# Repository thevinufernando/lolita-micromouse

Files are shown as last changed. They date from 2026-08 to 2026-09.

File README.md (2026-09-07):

# Lolita Micromouse

<table align="center">
  <tr>
    <td align="center" valign="middle">
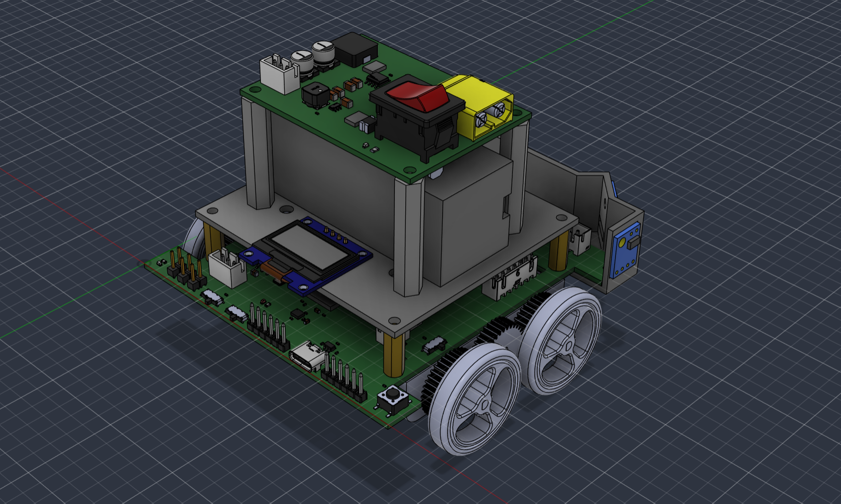
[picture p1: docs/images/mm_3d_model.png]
Lolita micromouse 3D model
      
    </td>
    <td width="24"></td>
    <td align="center" valign="middle">
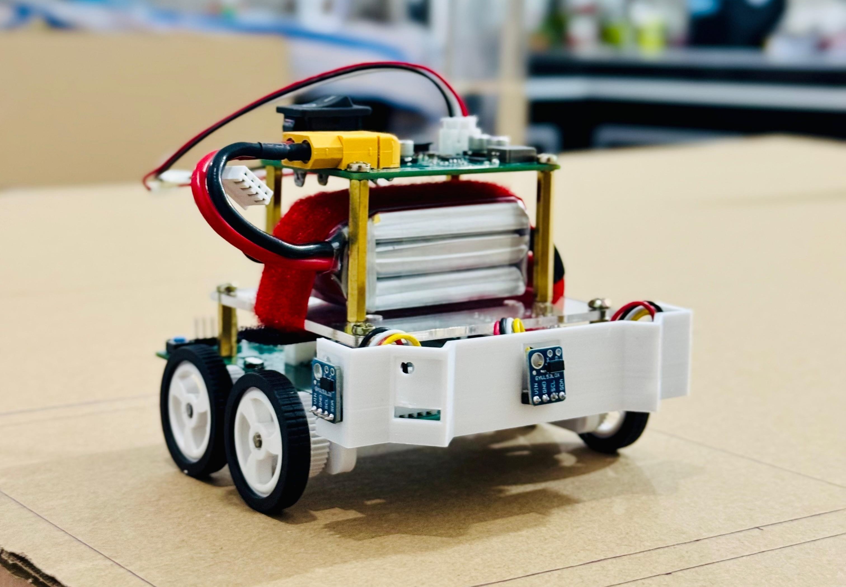
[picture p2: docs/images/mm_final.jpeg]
Lolita micromouse assembled robot
      
    </td>
  </tr>
</table>

## About

Lolita is a differential-drive micromouse robot built around an
**STM32F405RGT6** MCU, a 6-axis IMU, encoder-equipped DC motors, and five
VL53L0X time-of-flight sensors for wall detection. Two custom 4-layer PCBs
(a power board and a main controller board) handle regulation, sensing, and
motor drive, all housed in a custom-designed 3D-printed chassis.

The firmware runs low-level motion control — encoder-only straight-line
motion and IMU/encoder-fused turns via an EKF — as the foundation for future
maze-solving. See [`main_controller/`](main_controller) for firmware details
and [`pcb_designs/`](pcb_designs) for the electrical design.

## Workspace structure

| Folder | Contents |
|---|---|
| [`main_controller/`](main_controller) | STM32 firmware (CubeMX + HAL, CMake/Ninja build) |
| [`pcb_designs/`](pcb_designs) | Altium schematics, PCB layouts, and bring-up tests for the Power and Main PCBs |
| [`mechanical_designs/`](mechanical_designs) | Chassis and mechanical CAD |
| [`simulations/`](simulations) | Simulation work |
| [`tests/`](tests) | Project-level test resources |
| [`docs/`](docs) | Documentation assets (images, etc.) |

Each folder has its own `README.md` with further detail.

## Cloning and building

```sh
git clone git@github.com:thevinufernando/lolita_micromouse.git
cd lolita_micromouse
```

Firmware build instructions (toolchain setup, flashing, and debugging) are in
[`main_controller/README.md`](main_controller/README.md). Hardware design
files under `pcb_designs/` require [Altium Designer](https://www.altium.com/)
or the free [Altium 365 Viewer](https://www.altium.com/viewer).

## Team

- Thevinu Fernando
- Hiruna Malavipathirana
- Ishakya Ranhiru
- Chanul Nimadith

<!-- Team photo to be added -->

## License

This project is licensed under the [MIT License](LICENSE).

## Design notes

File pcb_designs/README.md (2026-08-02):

# PCB Designs

This folder contains the electrical design of the micromouse robot: schematics, PCB layouts, 3D renders, bring-up test media, and supporting design documents. The design is split into two boards — a **Power PCB** and a **Main Controller PCB** — connected by a board-to-board power harness.

All designs were done in Altium Designer. Both boards are **4-layer** PCBs.

## Folder structure

```
pcb_designs/
├── assets/                          # Schematic, layout, and 3D render images (used below)
├── docs/
│   └── LMR14030SDDAR_webench_reports/  # TI WEBENCH design reports for the 6V buck converter
├── main_PCB/
│   ├── schematics/                  # MM_2.0_sch.SchDoc + exported PDF
│   └── pcb/                         # MM_2.0_pcb.PcbDoc
├── power_PCB/
│   ├── schematics/                  # MM_2.0_power_sch.SchDoc + exported PDF
│   └── pcb/                         # MM_2.0_power_pcb.PcbDoc
└── tests/
    ├── main_PCB/                    # Bring-up photos/videos of the main PCB
    └── power_PCB/                   # Buck converter output tests (6V / 3.3V rails)
```

> Note: `.SchDoc` and `.PcbDoc` files require [Altium Designer](https://www.altium.com/) (or the free [Altium 365 Viewer](https://www.altium.com/viewer)) to open. PDF exports of the schematics are included alongside the source files for quick viewing without Altium.

## System overview

The robot is powered by a single **3S LiPO battery (11.1V nominal / 12.6V full charge)**. The Power PCB steps this down to the two rails the rest of the system needs, and the Main PCB carries the MCU, sensors, and motor drive electronics.

```
3S LiPO (12.6V) ──> Power PCB ──> +6V  (motors, via DRV8833)
                               └─> +3.3V (STM32, IMU, ToF sensors, OLED, logic)
```

---

## Power PCB

The Power PCB converts the raw battery voltage into two clean regulated rails using synchronous buck converters, with input reverse-polarity/overcurrent protection and a physical power switch.

### Key sections (see [power_PCB_sch.png](assets/power_PCB_sch.png))

| Section | Description |
|---|---|
| **Battery Power Supply** | XT60 connector (`J1`) brings in raw `VBAT` (3S LiPO, ~12.6V max). |
| **Circuit Protection** | Series power switch (`S1`), a resettable fuse (`F1`, 1812L300/24SLER) and a reverse-polarity/flyback protection diode (`D2`, PDS760-13) on the `VBAT_SW` → `VBAT_REG` path, with bulk input capacitance (`C12`). |
| **VBAT → +3.3V Conversion** | `AP63203WU-7` synchronous buck converter (`U1`) steps `VBAT_REG` down to a fixed **+3.3V** rail (`+3V3_BUCK`) for MCU/logic. |
| **VBAT → +6V Conversion** | `LMR14030SDDAR` synchronous buck converter (`U2`) steps `VBAT_REG` down to a regulated **+6V** rail (`+6V_BUCK`) for the drive motors. Output voltage is set via the `R2`/`R3` feedback divider. |
| **Power Output** | 3-pin JST connector (`J2`) exports `+6V_BUCK`, `+3V3_BUCK`, and `GND` to the Main PCB. |
| **Power LED** | `D3` indicator LED shows the board is powered from `VBAT_REG`. |

### Buck converter design notes

- **+3.3V rail — AP63203WU-7**: a simple fixed-frequency synchronous buck, chosen for the low-current 3.3V logic rail (MCU, sensors, OLED).
- **+6V rail — LMR14030SDDAR**: drives the higher-current motor rail. This converter was designed and simulated using **TI WEBENCH** — see [`docs/LMR14030SDDAR_webench_reports`](docs/LMR14030SDDAR_webench_reports) for the full design report, including:
  - `webench_sch.pdf` — WEBENCH-generated reference schematic
  - `WBDesign1_Steady State-1.pdf` — steady-state output ripple/efficiency
  - `WBDesign1_Bode Plot-2.pdf` — loop stability (gain/phase margin)
  - `WBDesign1_Startup-3.pdf` — startup/soft-start behavior
  - `WBDesign1_Input Transient-4.pdf` — response to input voltage transients

### Layout & 3D render

| Schematic | Layout | 3D View |
|---|---|---|
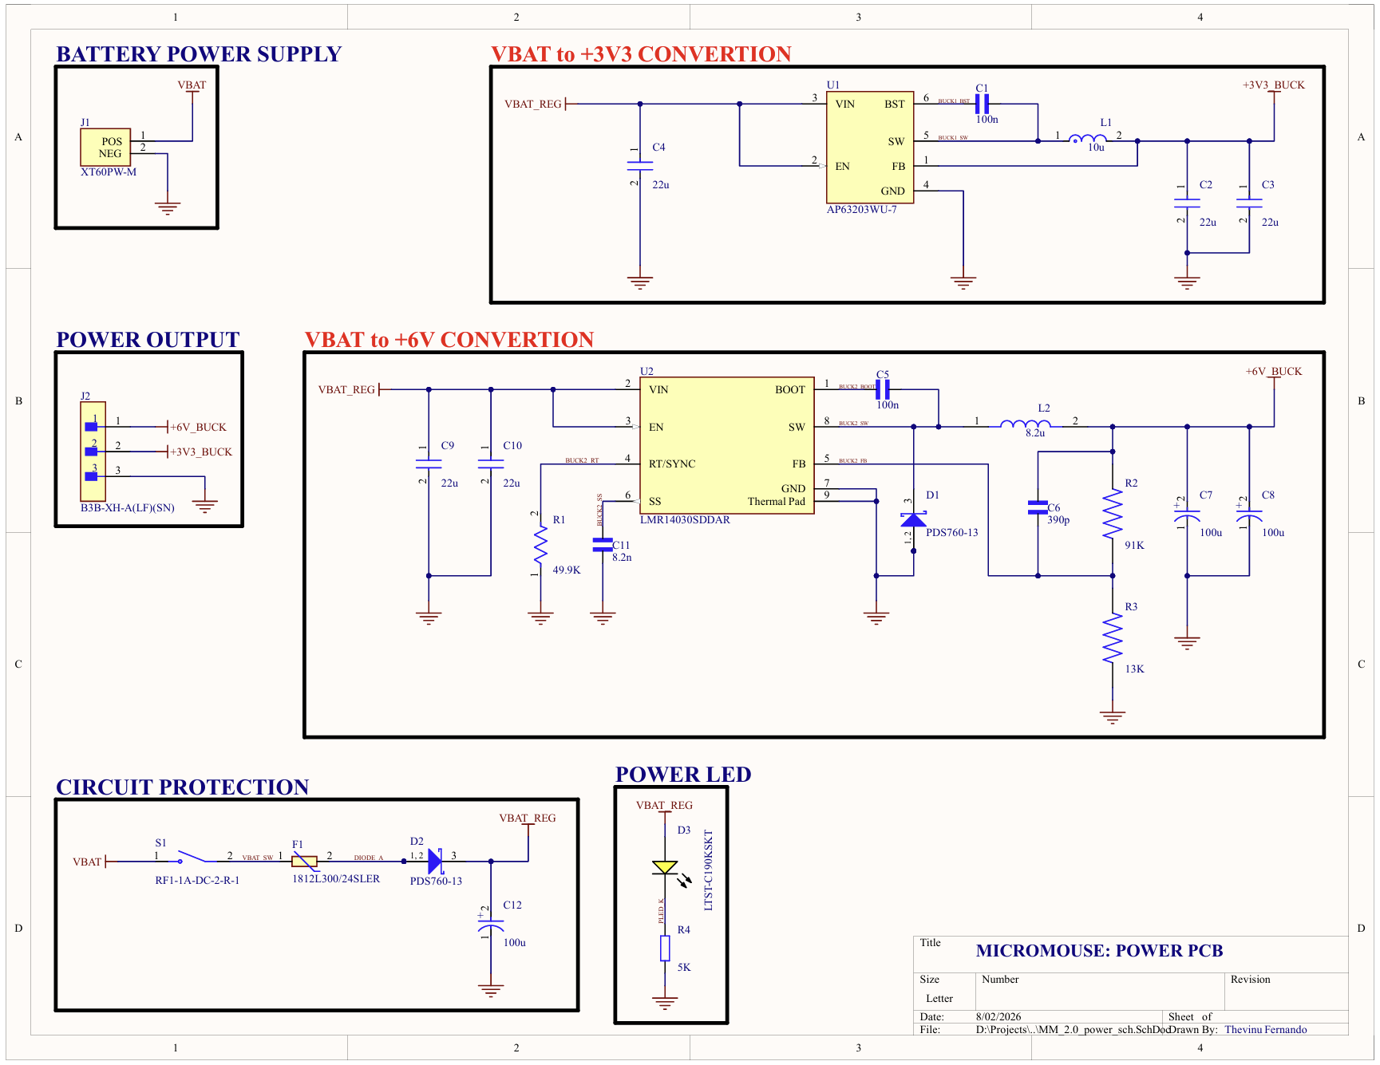
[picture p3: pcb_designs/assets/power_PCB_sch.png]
Power PCB Schematic
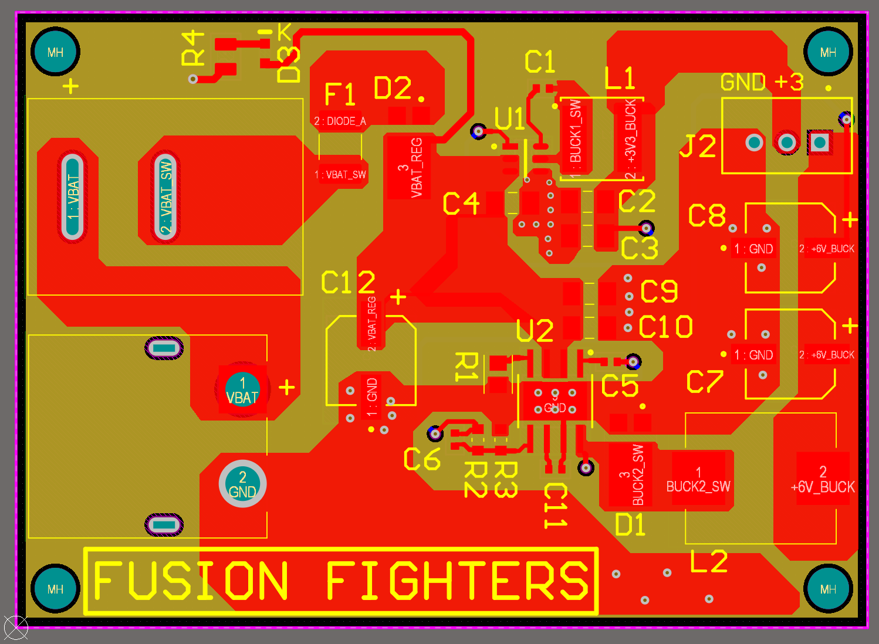
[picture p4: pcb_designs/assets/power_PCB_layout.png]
Power PCB Layout
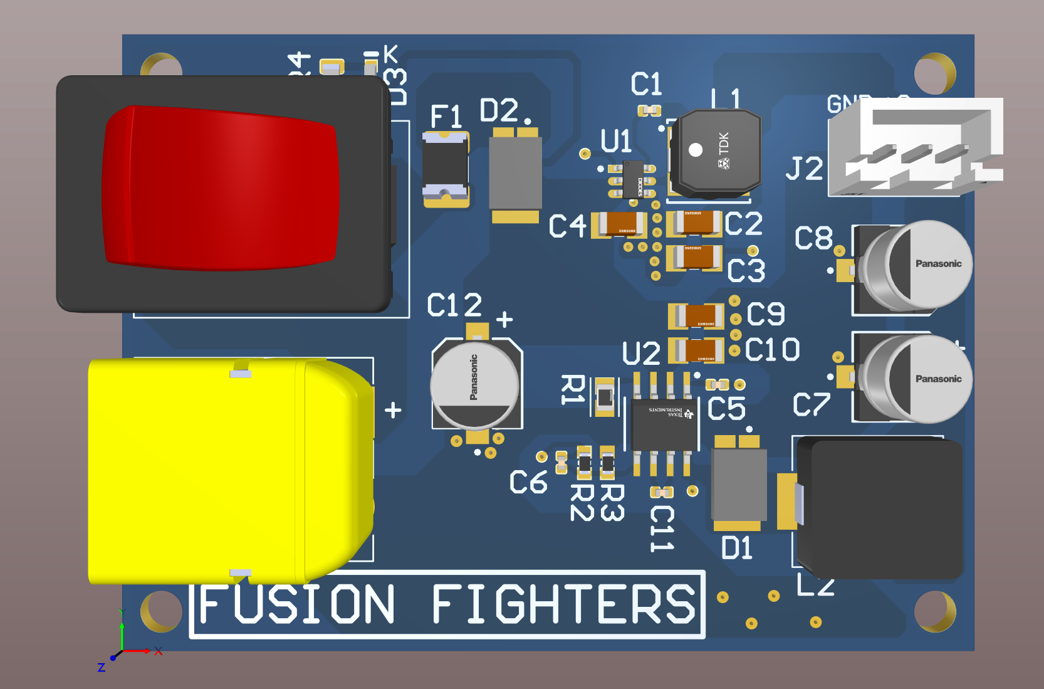
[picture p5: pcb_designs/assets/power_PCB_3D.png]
Power PCB 3D
|  |  |  |

### Bring-up testing

The Power PCB was bench-tested to verify both regulated rails before integrating with the Main PCB:

- [`tests/power_PCB/power_PCB_test.JPEG`](tests/power_PCB/power_PCB_test.JPEG) — test setup
- [`tests/power_PCB/6V_buck_test.MP4`](tests/power_PCB/6V_buck_test.MP4) — +6V rail verification
- [`tests/power_PCB/3.3V_buck_test.MP4`](tests/power_PCB/3.3V_buck_test.MP4) — +3.3V rail verification

---

## Main Controller PCB

The Main PCB carries the STM32F405RGT6 MCU, all sensing, motor driving, and the debug/expansion interfaces. It receives regulated +6V and +3.3V from the Power PCB.

### Key sections (see [main_PCB_sch.png](assets/main_PCB_sch.png))

| Section | Description |
|---|---|
| **MCU** | `STM32F405RGT6` (`U1A`/`U1B`) — main controller, running the firmware in [`main_controller/`](../main_controller). |
| **USB 2.0 (USB-C)** | USB-C receptacle with CC1/CC2 pull-downs for UFP detection, ESD protection (`USBLC6-2SC6`), and a `LDL1117S33R` LDO generating `+3V3_USB` for the USB PHY. |
| **Power Selection** | Jumper-selectable MCU supply source — `+3V3_USB` (from USB), `+3V3_EXT` (from the Power PCB), or `+3V3_DEBUG` (from an external debug supply). |
| **External Power Supply** | Direct `+6V_EXT` / `+3V3_EXT` input connector, for bench testing without the Power PCB. |
| **Inertial Measurement Unit** | `ICM-42688-P` 6-axis IMU (`U3`) over SPI, with its own 24MHz-independent decoupling and `IMU_INT` interrupt line to the MCU. |
| **VL53L0X ToF Sensors (I2C)** | Five VL53L0X time-of-flight distance sensors (`J4`–`J8`), one per wall-detection direction. |
| **TCA9548A I2C Mux** | 8-channel `TCA9548A` I2C multiplexer (`U4`). Since all VL53L0X units share the same default I2C address, each sensor is wired to its own mux channel so the MCU can address them individually over a single I2C bus. |
| **DRV8833 Motor Driver** | Dual H-bridge `DRV8833` driver ICs (one per motor, `J12`/`J13`) driving the left and right DC motors from the `+6V_EXT` rail, controlled via PWM from the MCU timers. |
| **Motors & Encoders (LM/RM)** | JST connectors (`J10`/`J11`) for the left/right motor + quadrature encoder channels (`ENC_CHA`/`ENC_CHB`) feeding the MCU's encoder timer inputs. |
| **OLED Display (I2C)** | 4-pin I2C header (`J9`) for a status/debug OLED. |
| **Debugging Interface** | SWD header (`J1`: `SWDIO`/`SWCLK`/`SWO`/`NRST`) for programming and debugging via ST-Link. |
| **BOOT0 / BOOT1 Mode Selection** | Slide switches to select MCU boot mode (system bootloader vs. flash) for DFU flashing. |
| **Mode Switches / External GPIO** | General-purpose slide switches (`MOD_SWA/SWB/SWM`) and a spare GPIO header (`J14`) for run-mode selection and future expansion. |
| **LED Indication** | Discrete status LEDs (`D2`/`D3`) driven directly from MCU GPIOs. |
| **Crystal / NRST / BOOT** | 24MHz HSE crystal (`X1`), reset button (`S5`), and boot-mode strapping circuitry for the MCU. |

### Layout & 3D render

| Schematic | Layout | 3D View |
|---|---|---|
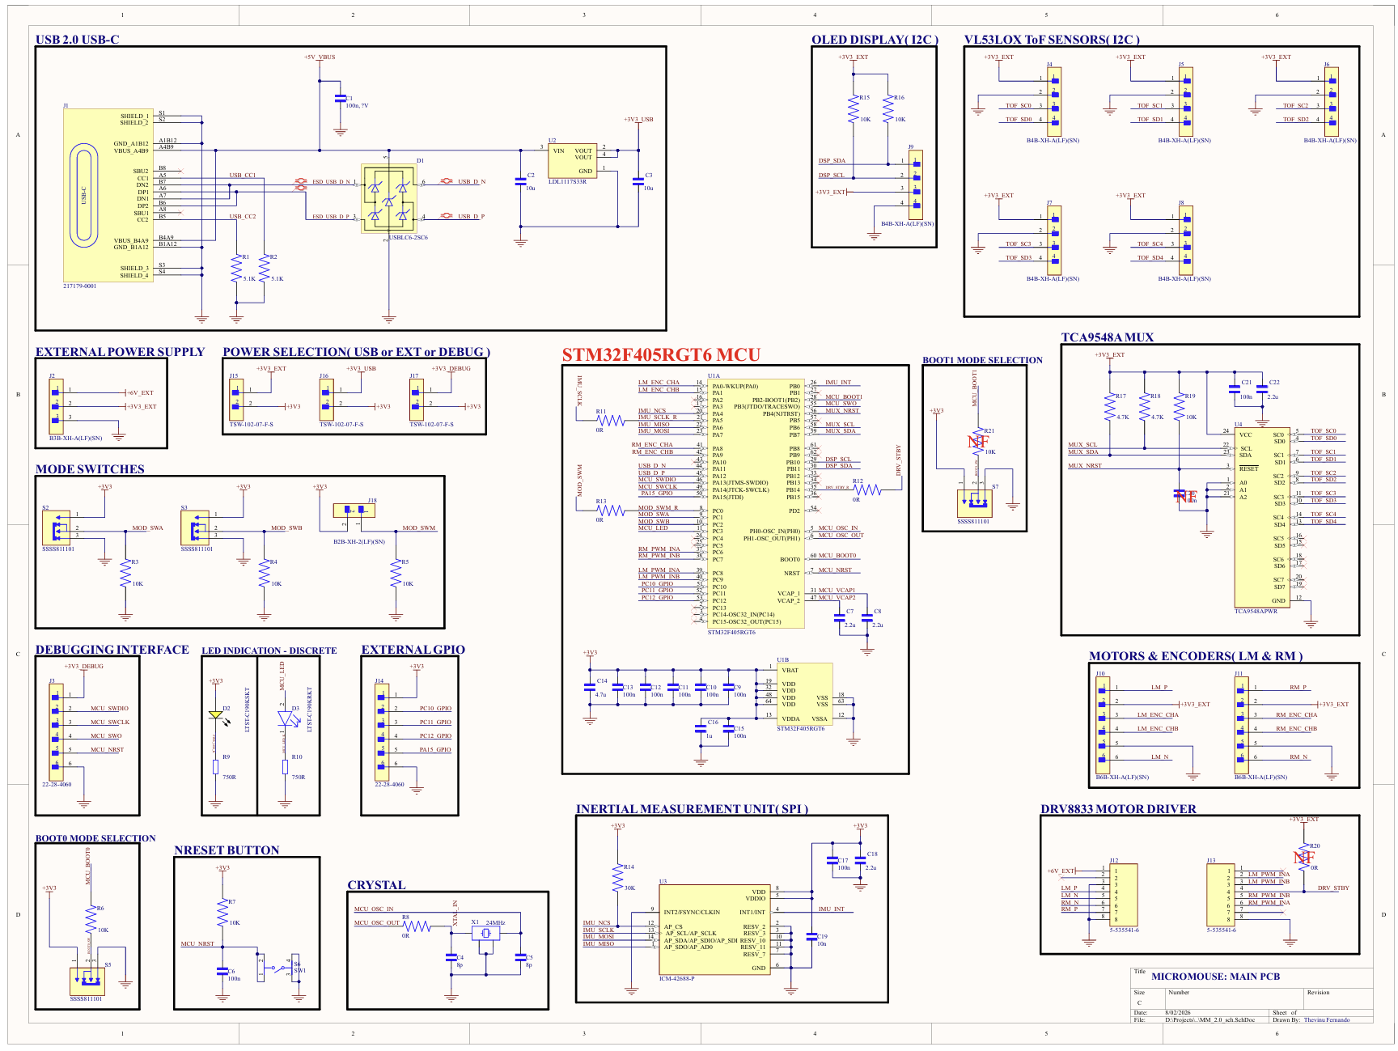
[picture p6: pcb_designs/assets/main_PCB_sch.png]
Main PCB Schematic
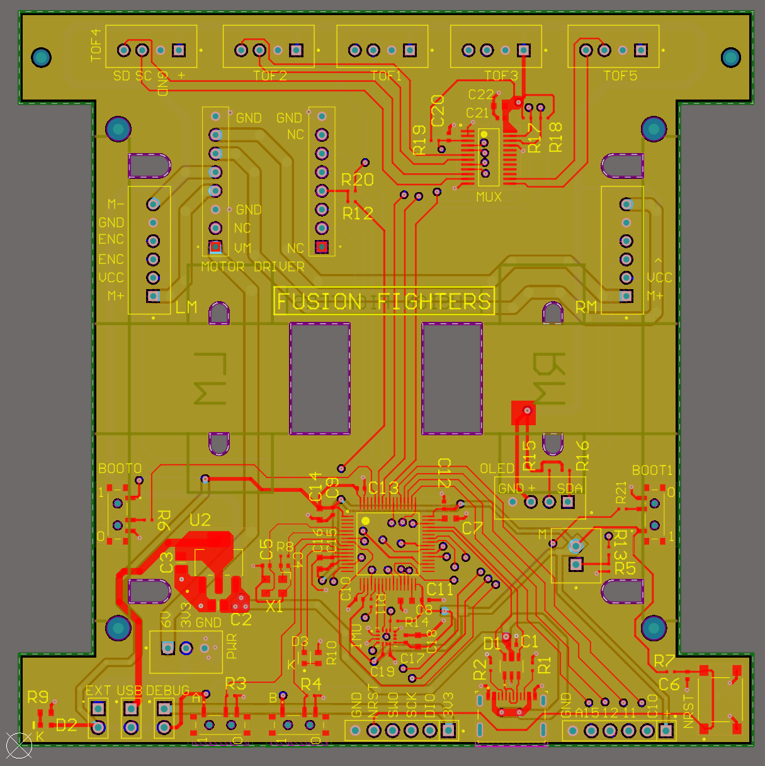
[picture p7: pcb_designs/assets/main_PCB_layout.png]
Main PCB Layout
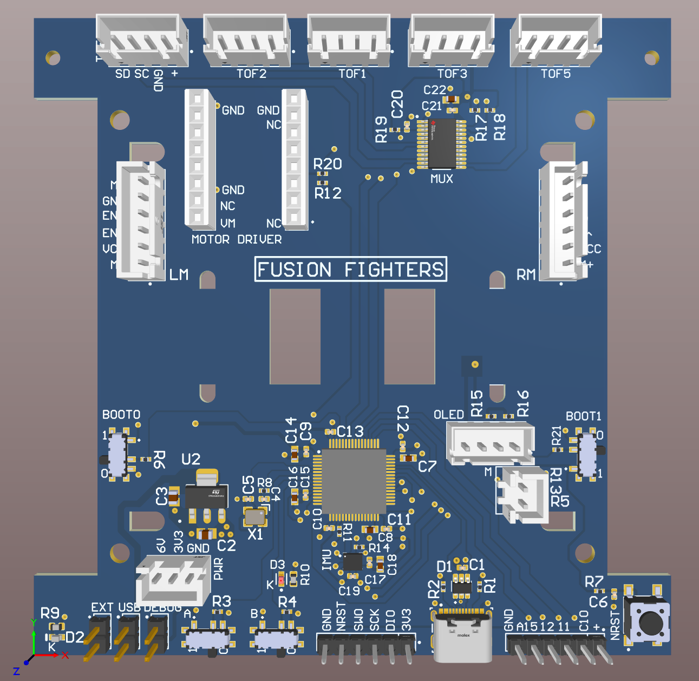
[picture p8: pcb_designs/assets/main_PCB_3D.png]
Main PCB 3D
|  |  |  |

### Bring-up testing

- [`tests/main_PCB/pcb_test_img.jpg`](tests/main_PCB/pcb_test_img.jpg) — assembled board
- [`tests/main_PCB/pcb_test.MP4`](tests/main_PCB/pcb_test.MP4) — power-up / basic functionality test
- [`tests/main_PCB/main_PCB_test.MP4`](tests/main_PCB/main_PCB_test.MP4) — extended functional test

---

## Design summary

| | Power PCB | Main PCB |
|---|---|---|
| Layers | 4 | 4 |
| Input | 3S LiPO (12.6V max) via XT60 | +6V / +3.3V from Power PCB (or external/USB) |
| Output | +6V, +3.3V | — |
| Key ICs | AP63203WU-7, LMR14030SDDAR | STM32F405RGT6, ICM-42688-P, TCA9548A, 5× VL53L0X, DRV8833 ×2 |
| CAD tool | Altium Designer | Altium Designer |

## Related documentation

- Firmware for the STM32F405RGT6 running on the Main PCB: [`main_controller/`](../main_controller) (see its `CLAUDE.md` for firmware development notes — **not covered by this document**).

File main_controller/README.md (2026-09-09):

# Main Controller — Firmware

This folder contains the firmware for the micromouse's main controller board:
an **STM32F405RGTx** (Cortex-M4F) running low-level motion control for the
differential-drive robot. It's built on **STM32CubeMX + HAL**, developed with
the **STM32Cube VSCode extension**, and built via **CMake + Ninja**.

> For the electrical design this firmware runs on, see
> [`pcb_designs/`](../pcb_designs) (Main Controller PCB section).

For the full technical reference used in day-to-day development — hardware
pin/peripheral map, sign/unit conventions, control architecture, tuning
procedure, hardware quirks, and change log — see **[CLAUDE.md](CLAUDE.md)**.
This README covers the same ground at a higher level plus environment setup.

---

## Current status

The robot is in **low-level controls bring-up**. Straight-line motion and
pivot turns are working and tunable. Maze-solving is **not implemented** and
out of scope until the motion primitives are trusted. The VL53L0X ToF sensors
are present on the PCB but not yet integrated into firmware.

## Hardware summary

| Part | Detail |
|---|---|
| MCU | STM32F405RGTx, Cortex-M4F, SYSCLK 96 MHz / **HCLK 48 MHz** |
| Motors | 2× N20 gear motor w/ quadrature encoder, differential drive |
| Motor driver | DRV8833 (IN/IN mode, 4 PWM channels) |
| IMU | ICM-42688-P (accel + gyro) over SPI1 — no magnetometer |
| Range | VL53L0X ToF ×5 — hardware present, not yet wired into firmware |
| Power | 3S LiPo, regulated by the companion Power PCB |

There is **no UART**. All runtime observation happens through the ST-Link
debugger's live-watch panel (`.vscode/launch.json` has the watch list
pre-populated), which is why the firmware exposes many `volatile` telemetry
globals.

## Firmware architecture

```
                 ┌──────────────┐
   encoders ────►│              │
                 │   EKF (yaw,  │──► fused yaw ──► turn PID ──► motors
   gyro Z ──────►│  gyro bias)  │
                 └──────────────┘

   encoders ────► distance PID ─┐
                                ├──► motors     (straight line, no IMU)
   encoders ────► heading  PID ─┘
```

- **Straight-line motion** is encoder-only by design.
- **Turns** fuse gyro + encoder odometry through a 2-state EKF (`[yaw, gyro_bias]`),
  running a multi-rate loop (~1 kHz gyro prediction, 100 Hz encoder
  correction + PID + motor output).
- All tuning constants live in a single file:
  `Core/Inc/Control/LowLevel/control_config.h`.
- `Core/Inc/Tests/test_harness.h` selects one of several on-target test
  routines (`ACTIVE_TEST`), implemented in `Core/Src/Tests/test_harness.c` —
  motor/encoder checks, straight-line tuning, turn tuning, IMU bring-up, etc.
  `main.c` itself only brings up hardware and calls `TestHarness_RunCycle()`.
  See [CLAUDE.md §6](CLAUDE.md#6-tuning-and-bring-up) for the full list and
  recommended bring-up order.

## Folder layout

```
main_controller/
├── Core/
│   ├── Inc, Src/
│   │   ├── Control/LowLevel/   PID.c  EKF.c  straightline_controller.c  turn_controller.c
│   │   │                       control_config.h  ← all tuning lives here
│   │   ├── Encoders/           encoders.c
│   │   ├── Motors/             DRV8833.c
│   │   ├── Sensors/ICM-42688-P/ ICM42688.c
│   │   ├── Tests/               test_harness.c  ← ACTIVE_TEST + all Test_* routines
│   │   └── Utils/               dwt_timer.c
├── Drivers/                    CMSIS + STM32F4xx HAL
├── cmake/                      Toolchain files + CubeMX-generated CMakeLists
├── tests/                      Host-side EKF verification harness (see tests/README.md)
├── main_controller.ioc         STM32CubeMX project file (pin/clock/peripheral config)
├── CMakeLists.txt              User source list — edit this to add files
├── CMakePresets.json           Debug / Release presets
└── STM32F405XX_FLASH.ld, startup_stm32f405xx.s
```

CubeMX owns the generated regions of `main.c` and all of
`cmake/stm32cubemx/CMakeLists.txt`. Hand-written code must stay inside
`/* USER CODE BEGIN x */ … /* USER CODE END x */` blocks or it will be
overwritten on the next CubeMX regeneration.

---

## Setup: STM32CubeIDE / STM32Cube extension for VSCode

This project is developed and built using the **STM32Cube for VSCode**
extension (ST's official STM32CubeIDE tooling brought into VSCode), not
standalone STM32CubeIDE.

### 1. Prerequisites

- [Visual Studio Code](https://code.visualstudio.com/)
- The **STM32Cube** extension pack from the VSCode Marketplace (search
  `STMicroelectronics` / `STM32Cube`). Installing it pulls in the required
  toolchain bundles (ARM GCC, CMake, Ninja, OpenOCD/ST-Link tools) under
  `%LOCALAPPDATA%\STM32Cube\bundles` — no separate STM32CubeIDE install is
  required.
- An **ST-Link** debug probe connected via the board's SWD header
  (`SWDIO`/`SWCLK`/`SWO`/`NRST`).
- (Optional, only if you need to regenerate peripheral init code)
  [STM32CubeMX](https://www.st.com/en/development-tools/stm32cubemx.html), to
  edit `main_controller.ioc`.

### 2. Open the project

1. Launch VSCode and open the `main_controller/` folder directly (this
   folder, not the repo root) — the extension expects the `.ioc` file,
   `CMakeLists.txt`, and `.vscode/` config at the workspace root.
2. The STM32Cube extension should auto-detect the project via
   `main_controller.ioc` and `.mxproject`. If prompted to configure CMake
   Tools, let it use the settings already checked into `.vscode/settings.json`
   (`cmake.cmakePath: cube-cmake`, Ninja generator).

### 3. Build

The extension drives CMake + Ninja under the hood using the `Debug` /
`Release` presets in `CMakePresets.json`. Use the extension's build button /
CMake Tools status bar, or run it manually.

To build from a shell instead, the ARM toolchain isn't on `PATH` by default —
add the bundled tools first:

```sh
BUNDLES="$LOCALAPPDATA/STM32Cube/bundles"
export PATH="$BUNDLES/gnu-tools-for-stm32/14.3.1+st.2/bin:$BUNDLES/ninja/1.13.2+st.1/bin:$PATH"
cmake --preset Debug        # only needed after adding/removing source files
cmake --build --preset Debug
```

The build must stay **warning-free**.

### 4. Flash and debug

Use the extension's **Run/Debug** panel (or `.vscode/launch.json`), which
flashes over the connected ST-Link and starts a debug session with the
pre-populated **live-watch** expression list — this is the primary way to
observe robot state, since there is no UART output.

> **Do not modify the `preBuild` / `imagesAndSymbols` settings in
> `.vscode/launch.json`.** Only the `liveWatch` expressions array is safe to
> edit freely (e.g. to add a new telemetry variable while tuning).

### 5. Adding a new source file

Two steps, both required, regardless of which tool you use to build:

1. Add it to `CMakeLists.txt` (`target_sources`, and
   `target_include_directories` if it's a new folder).
2. Re-run `cmake --preset Debug` (or reconfigure via the extension) so Ninja
   picks it up.

Never add user sources to `cmake/stm32cubemx/CMakeLists.txt` — it's
regenerated by CubeMX and anything added there is lost.

### 6. Regenerating peripheral code (STM32CubeMX)

If you need to change pin assignments, clocks, or enable a new peripheral,
edit `main_controller.ioc` in STM32CubeMX and regenerate. This rewrites
`cmake/stm32cubemx/` and the generated regions of `main.c`/HAL init files —
hand-written code inside `USER CODE` blocks is preserved, everything else is
not.

---

## Host-side tests

`tests/` contains a standalone host harness that compiles and exercises the
EKF (`Core/Src/Control/LowLevel/EKF.c`) on the development machine against
simulated sensor data, independent of the STM32 build. Run it after any
change to `EKF.c`:

```sh
gcc -O1 -o ekf_test.exe tests/ekf_host_test.c Core/Src/Control/LowLevel/EKF.c \
    -I Core/Inc/Control/LowLevel -lm
./ekf_test.exe
```

See [`tests/README.md`](tests/README.md) for what each test case covers.

---

## Conventions at a glance

Full detail is in [CLAUDE.md](CLAUDE.md) — summarized here:

- **Positive yaw = anticlockwise = left turn**, consistently across encoders,
  gyro, EKF, and PID.
- Distance in **cm**, turn angle in **degrees**, EKF yaw in **continuous,
  unwrapped radians**, motor speed **0–255 signed**.
- There is no magnetometer, so absolute heading is impossible — yaw is always
  relative to the last reset.

## Related documentation

- [CLAUDE.md](CLAUDE.md) — full firmware development reference (peripheral
  map, EKF derivation notes, tuning workflow, hardware quirks, change log).
- [`tests/README.md`](tests/README.md) — EKF host test details.
- [`../pcb_designs/README.md`](../pcb_designs/README.md) — electrical design
  this firmware targets.

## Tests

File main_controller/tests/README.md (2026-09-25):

# Host-side tests

Seven suites live here. Most compile real firmware sources on the development
machine and run them against simulated data, so they catch maths errors that
on-target testing cannot: on hardware you can only watch the output, whereas
here it can be compared against a known ground truth. The rest mirror logic that
cannot be linked on the host because it needs the HAL or the ST API, and pin the
RULE rather than the plumbing.

| Suite | Covers | Run after changing |
|---|---|---|
| `ekf_host_test.c` | Yaw EKF (gyro + encoder fusion) | `EKF.c` |
| `tof_filter_host_test.c` | VL53L0X noise filter | `tof_filter.c` |
| `tof_cache_host_test.c` | Held-reading age gate | `tof_sensors.c`, `TOF_MAX_SAMPLE_AGE_MS` |
| `motion_profile_host_test.c` | Trapezoidal profiles, mid-move retargeting, **moves that end at speed** | `motion_profile.c`, `CELL_DECISION_OFFSET_CM` |
| `maze_map_host_test.c` | Pose, wall bookkeeping, known-vs-open | `maze_map.c` |
| `navigator_host_test.c` | Reactive wall-following rule | `navigator.c` |
| `wall_follow_host_test.c` | Lateral loop and the cascade rule | `wall_follow.c`, the `WALL_FOLLOW_*` constants |
| `floodfill_goal_latch_test.c` | The goal-completion ordering window | `floodfill_run.c`, and upstream `Main.c` |
| `floodfill_diff.sh` | **That the ported flood fill IS the original** | anything under `Core/*/Maze/floodfill/` |

> **The maze state moved.** `v_walls`, `h_walls` and the pose are defined by the
> algorithm now (`Core/Src/Maze/floodfill/floodfill_run.c`), not by
> `maze_map.c`, so any test that links the map also has to link the algorithm
> and a stub API. The build lines below already do.

---

## EKF

`ekf_host_test.c` compiles the real `Core/Src/Control/LowLevel/EKF.c` on the
development machine and runs it against simulated sensor data. The EKF has no
hardware dependencies (it includes only `EKF.h`, `control_config.h` and
`math.h`), so it can be exercised without flashing the robot.

This is the only practical way to verify the filter maths. On-target you can
only observe the output; here you can compare it against a known ground truth.

## Running

Any host GCC will do (MSYS2 UCRT64 is what this project was developed with):

```sh
gcc -O1 -o ekf_test.exe tests/ekf_host_test.c Core/Src/Control/LowLevel/EKF.c \
    -I Core/Inc/Control/LowLevel -lm
./ekf_test.exe
```

Exit code is 0 when everything passes, 1 otherwise.

## What it covers

| Test | Checks |
|---|---|
| 1 | Gyro bias is recovered from a stationary run where the gyro reports rotation but the encoders do not |
| 2 | A clean 90 deg turn produces 90 deg of fused yaw |
| 3 | A 30% wheel-slip scale error is rejected: encoder-only would read 117 deg, fused reads ~90 |
| 4 | Yaw stays continuous past 360 deg and `EKF_NormalizeAngle` wraps correctly |
| 5 | `EKF_Reset` zeroes yaw but preserves the learned gyro bias |
| 6 | Zero, negative, huge and NULL inputs cannot corrupt the state |

Every test also asserts that the covariance matrix stays symmetric and
positive-definite, which is the usual early warning that a Kalman filter has
gone numerically wrong.

## Note on test 3

Test 3 is what drove the `EKF_R_SLIP_COEFF` design. With a fixed measurement
noise the filter tracked the slipping encoders to 100.4 deg, because
innovation gating only rejects sudden outliers and a steady slip ramp does not
look like one. Making R grow with the square of the rotation rate brought that
to 90.45 deg. If you ever set `EKF_R_SLIP_COEFF` to 0, expect this test to
fail - that is the test doing its job, not a bug.

---

## ToF noise filter

`tof_filter_host_test.c` exercises `Core/Src/Sensors/VL53L0X_Driver/tof_filter.c`.
It depends only on `tof_filter.h` and `control_config.h`, so it needs no
hardware and no ST API.

### Running

```sh
gcc -O1 -o tof_filter_test.exe tests/tof_filter_host_test.c     Core/Src/Sensors/VL53L0X_Driver/tof_filter.c     -I Core/Inc/Sensors/VL53L0X_Driver -I Core/Inc/Control/LowLevel -lm
./tof_filter_test.exe
```

The simulated noise band (83-90 mm for a true 80 mm target) is taken from an
actual bench measurement on this robot, so the test reflects the real sensor
rather than an invented noise model.

### What it covers

| Test | Checks |
|---|---|
| 1 | Jitter is actually reduced (sigma 2.27 mm -> 0.94 mm) and the mean is preserved |
| 2 | The filter does **not** remove bias - it settles at the biased mean, not the truth |
| 3 | A real wall transition (86 -> 250 mm) is passed through immediately, not ramped |
| 4 | Ordinary jitter never trips the jump detector |
| 5 | A lone outlier does not persist beyond one sample |
| 6 | A freshly-reset filter never reports a false close wall |
| 7 | `Invalidate()` re-seeds cleanly without blending across the gap |
| 8 | Zero, huge and NULL inputs cannot corrupt the filter |

### Note on tests 2, 3 and 5

**Test 2 asserts a limitation, deliberately.** Noise and bias are different
problems: no filter can remove a constant offset, because the average of
biased samples is equally biased. It exists so nobody tries to fix a constant
error by tuning filter constants. Bias belongs to `TOF_OFFSET_*_MM`.

**Test 3 caught a real design defect.** The jump detector originally compared
the *median* against the threshold. But a genuine step arrives as one new
value against a window of old ones - `{86, 86, 250}` medians to `86` - so the
median stage suppressed the first sample of every real transition exactly as
if it were an outlier, and the robot stayed blind to an opening for two
further samples. The detector now tests the **raw** sample. Do not "tidy" it
to use the median.

**Test 5 documents the cost of that fix.** A median cannot distinguish a bad
reflection from the first sample of a real change - they are the same shape -
so an outlier larger than the threshold produces one sample of overshoot
before the median pulls it back. The test asserts it does not persist rather
than that it never happens. A one-sample blip is much cheaper than being blind
to a real opening in the maze.

## tof_cache_host_test.c - the held-reading age gate

```sh
gcc -O1 -Wall -Wextra -o tof_cache_test tests/tof_cache_host_test.c \
    -I Core/Inc/Control/LowLevel -lm && ./tof_cache_test
```

Mirrors the decision `ToF_ReadAllLatest()` makes when a free-running sensor has
nothing new yet. The driver cannot run on the host -- it pulls in the ST API and
the HAL -- so what is pinned here is the rule rather than the plumbing.

The rule exists because continuous ranging and a 10 ms control loop do not tick
together: three polls in four legitimately find nothing new. Reporting that as
an invalid measurement is honest and useless, because the wall follower reads
invalid as "no wall" and would drop and re-acquire its reference several times a
second. So the newest good reading is held and served.

The age limit is the other half. Without it a dead sensor is indistinguishable
from one merely between measurements, and its last reading would be served
forever while the robot steers to a wall that is no longer there.

Also pins the unsigned-subtraction idiom against the tick counter's 32-bit wrap,
where a signed comparison would call a brand-new reading ancient.

## maze_map_host_test.c - pose, wall bookkeeping, known-vs-open

```sh
gcc -O1 -Wall -Wextra -o maze_map_test tests/maze_map_host_test.c \
    Core/Src/Maze/maze_map.c Core/Src/Maze/floodfill/maze.c \
    Core/Src/Maze/floodfill/floodfill_run.c tests/floodfill_sim_api.c \
    -DSIM_PROVIDE_DEBUG_LOG -I Core/Inc/Maze -I Core/Inc/Maze/floodfill \
    && ./maze_map_test
```

Covers the direction arithmetic in both directions -- `MazeMap_CellWalls()`
must read back exactly what `MazeMap_UpdateWalls()` wrote, from all four
headings -- and the distinction between a cell with no walls and a cell nobody
has looked at. Getting the first wrong produces a map that is plausible,
self-consistent and mirrored; getting the second wrong makes every unexplored
cell read as wide open.

## floodfill_diff.sh - is the ported algorithm the same algorithm?

```sh
tests/floodfill_diff.sh [path-to-MicroMouseAlgorithm]
```

The one test that matters for the port. It builds `MicroMouseAlgorithm`'s
`maze.c` + `Main.c` into one binary and the copies under
`Core/{Inc,Src}/Maze/floodfill/` into another, links BOTH against the same
simulated maze in `floodfill_sim_api.c`, and compares their transcripts action
for action across seven seeded mazes.

Everything about the two builds is identical except which copy of the algorithm
they contain. So "the algorithm did not change" stops being a claim and becomes
something the build either proves or fails. Run it after touching anything
under `floodfill/`, and if it ever diverges, change
`MicroMouseAlgorithm` first and re-port rather than patching the copy.

It also runs every maze twice, once serving wall readings fresh and once from a
per-cell snapshot. The snapshot is the single adaptation the robot needed -- a
real sensor read costs about 200 ms and the algorithm asks several times per
cell -- and the transcripts must match, or the caching is changing behaviour
rather than just saving time.

The mazes come from a seeded recursive backtracker, so both binaries carve the
identical one and there are plenty of dead ends for `checkDeadEnd()` to find.

## navigator_host_test.c - reactive wall-following rule

```sh
gcc -O1 -Wall -Wextra -o nav_test tests/navigator_host_test.c \
    Core/Src/Maze/maze_map.c Core/Src/Maze/floodfill/maze.c \
    Core/Src/Maze/floodfill/floodfill_run.c tests/floodfill_sim_api.c \
    -DSIM_PROVIDE_DEBUG_LOG -I Core/Inc/Maze -I Core/Inc/Maze/floodfill \
    && ./nav_test
```

Checks the decision rule's truth table, then drives it around a simulated
arena through the real `maze_map.c` and asserts the recorded walls match.

**It caught the defining bug in that rule.** The first version returned "turn
right" as a complete action. The trace showed the robot reaching the opening,
turning into it, seeing another open right, and pivoting straight back down
the corridor it came from without ever entering the new cell. Every action a
wall follower takes must end in one cell of forward motion; the turn only
chooses which way to leave. This is the classic way the rule is written wrong,
and on hardware it would have looked like a turn-tuning problem rather than a
logic error.

The rule itself is copied into the test rather than linked, because
`navigator.c` needs the HAL and cannot build on the host. The constants come
from the real `navigator.h`, so the test also proves that header parses
standalone and that `MazeTrace_t` still satisfies its 40-byte stride assert.

---

## motion_profile_host_test.c - the chained-motion cases

```sh
gcc -O1 -Wall -Wextra -o prof_test tests/motion_profile_host_test.c \
    Core/Src/Control/LowLevel/motion_profile.c \
    -I Core/Inc/Control/LowLevel -lm && ./prof_test
```

Tests 8 to 10 cover `MotionProfile_InitFromTo()`, which is what continuous cell
motion is built on. They are worth calling out because a mistake in any of them
is invisible on a bench and expensive in a maze:

| Test | Checks |
|---|---|
| 8 | A cruise-to-cruise segment has NO ramps, takes exactly distance/speed, and beats the same cell driven rest-to-rest |
| 9 | The two ends of a chained corridor: leaving a centre accelerates and never decelerates; the stop before a turn comes to rest exactly at the centre with cruise to spare |
| 10 | A speed change with no room for it is REFUSED, and what gets built is the hardest stop rather than a reversal -- in both directions, plus a `v_end` pointing backwards |

A profile that quietly decelerated to rest anyway would look like the robot
merely being slow. One that overshot its distance would put the robot past the
point it can still stop at before a turn, which this chassis cannot recover
from -- it has no reverse.

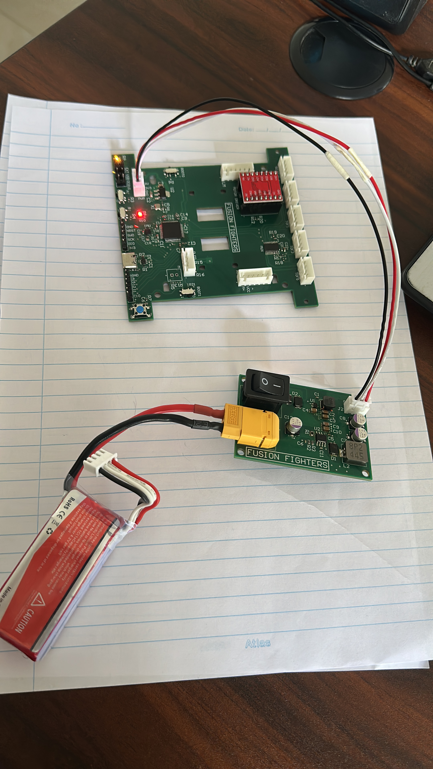
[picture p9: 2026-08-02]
pcb_designs/tests/main_PCB/pcb_test_img.jpg

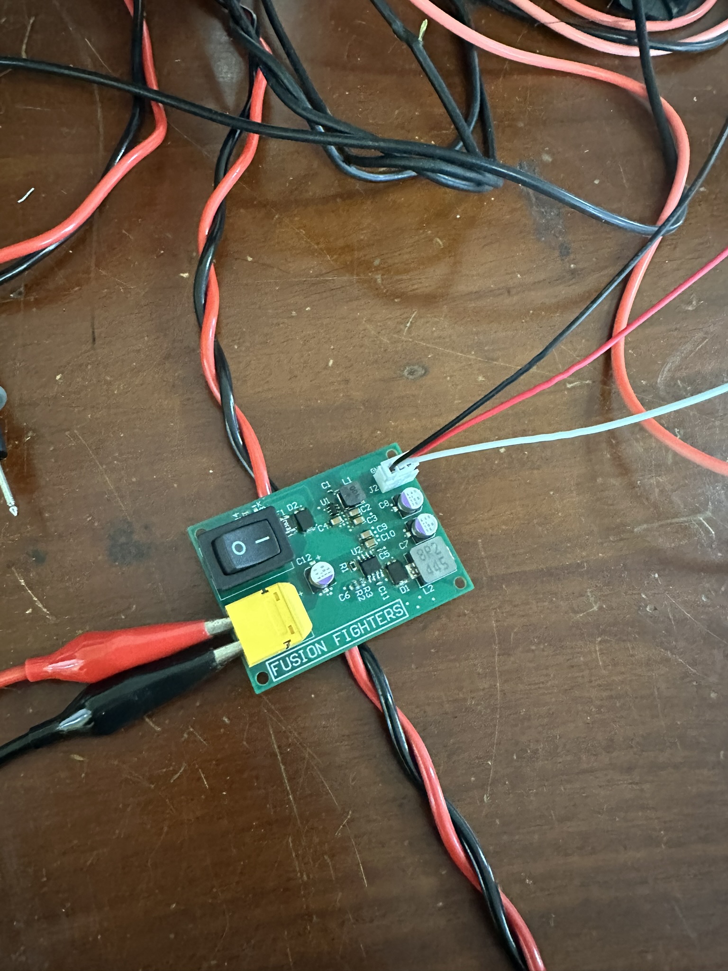
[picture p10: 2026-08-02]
pcb_designs/tests/power_PCB/power_PCB_test.JPEG

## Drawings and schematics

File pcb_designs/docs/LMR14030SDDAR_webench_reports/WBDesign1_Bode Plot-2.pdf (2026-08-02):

## WEBENCH ® Design Report

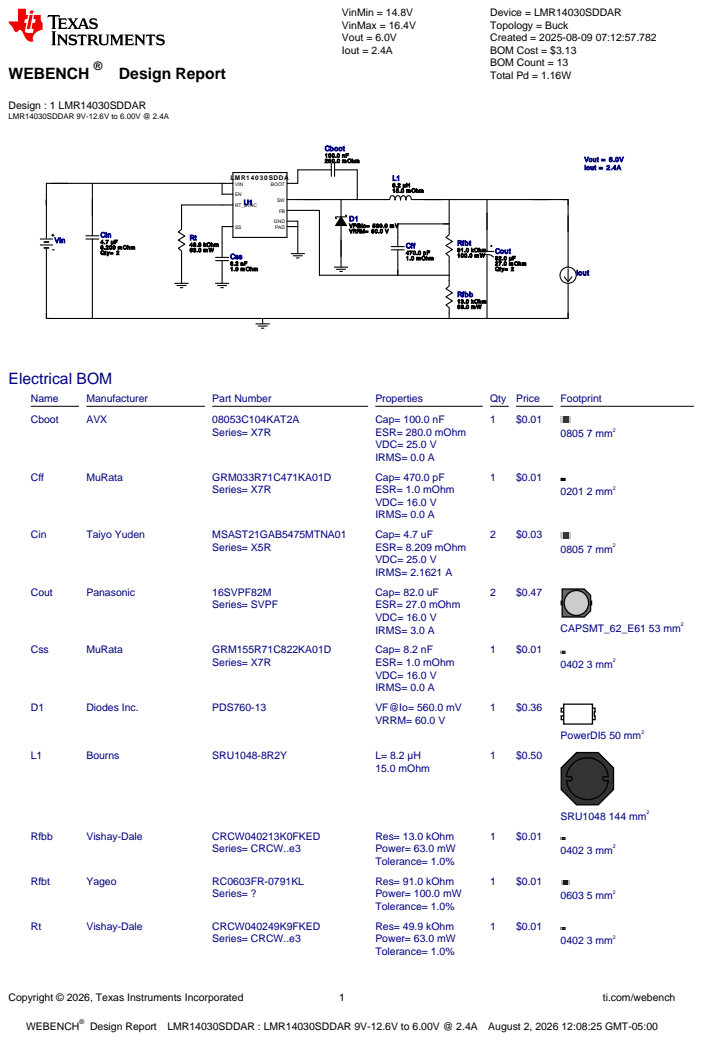
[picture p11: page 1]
Copyright © 2026, Texas Instruments Incorporated; ti.com/webench; WEBENCH®; Design : 1 LMR14030SDDAR LMR14030SDDAR 9V-12.6V to 6.00V @ 2.4A; VinMin = 14.8V VinMax = 16.4V Vout = 6.0V Iout = 2.4A; Device = LMR14030SDDAR Topology = Buck Created = 2025-08-09 07:12:57.782 BOM Cost = $3.13 BOM Count = 13 Total Pd = 1.16W; Css 8.2 nF 1.0 m Ohm; Vout = 6.0V Iout = 2.4A; Rfbb 13.0 kOhm 63.0 m W; Cout 82.0 µF 27.0 m Ohm Qty= 2; L1 8.2 µH 15.0 m Ohm; Cboot 100.0 nF 280.0 m Ohm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

Design Report LMR14030SDDAR : LMR14030SDDAR 9V-12.6V to 6.00V @ 2.4A August 2, 2026 12:08:25 GMT-05:00

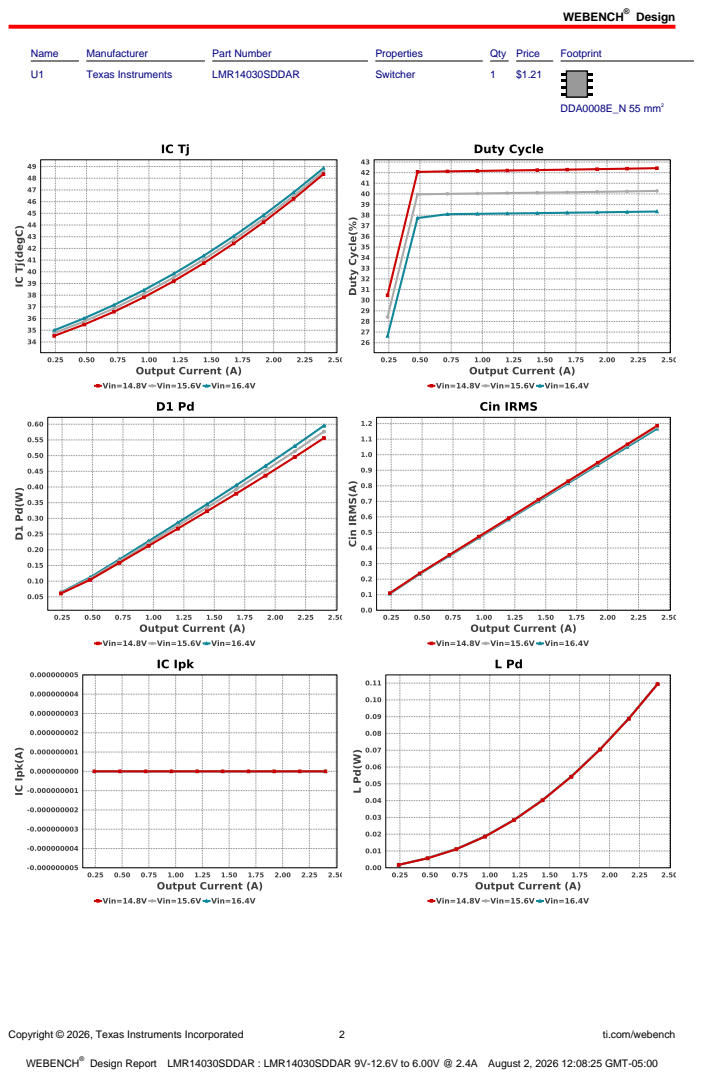
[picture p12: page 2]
Design; Copyright © 2026, Texas Instruments Incorporated; ti.com/webench; Name; Manufacturer; Part Number; Properties; Qty Price; Footprint; Texas Instruments; LMR14030SDDAR; Switcher; DDA0008E_N 55 mm²

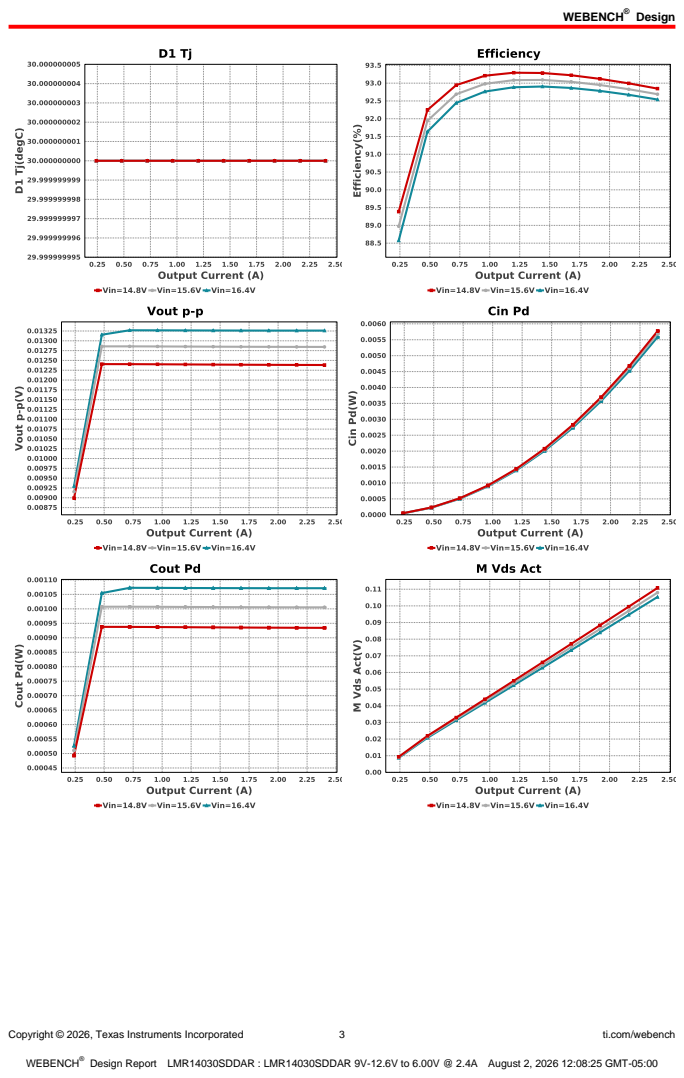
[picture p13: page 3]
Copyright © 2026, Texas Instruments Incorporated; ti.com/webench

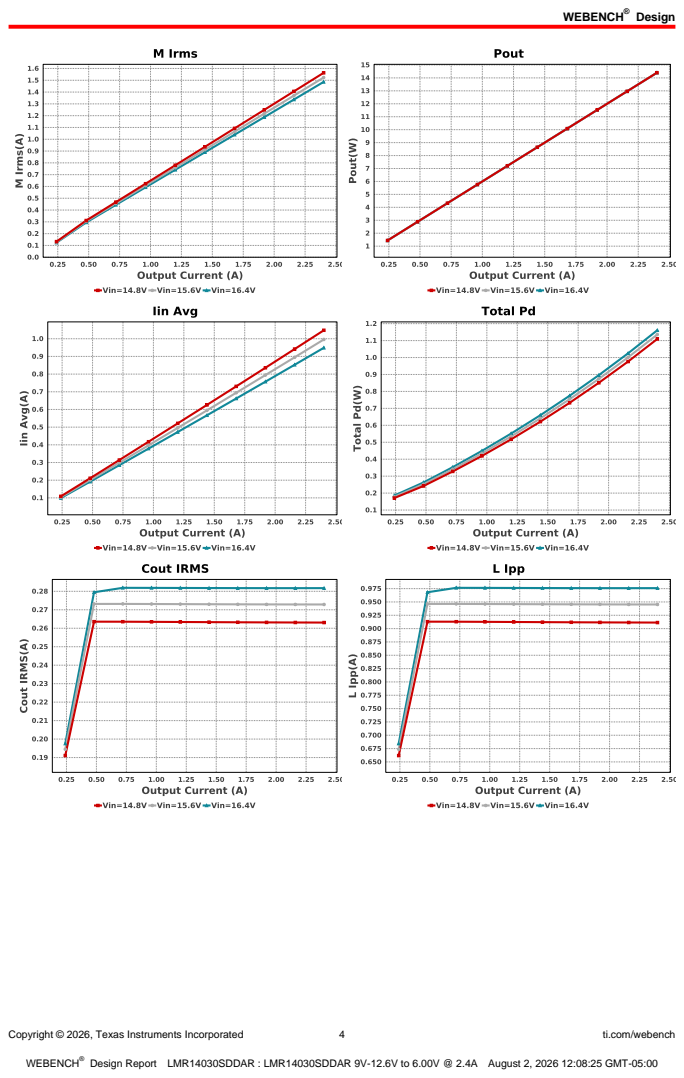
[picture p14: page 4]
Copyright © 2026, Texas Instruments Incorporated; ti.com/webench

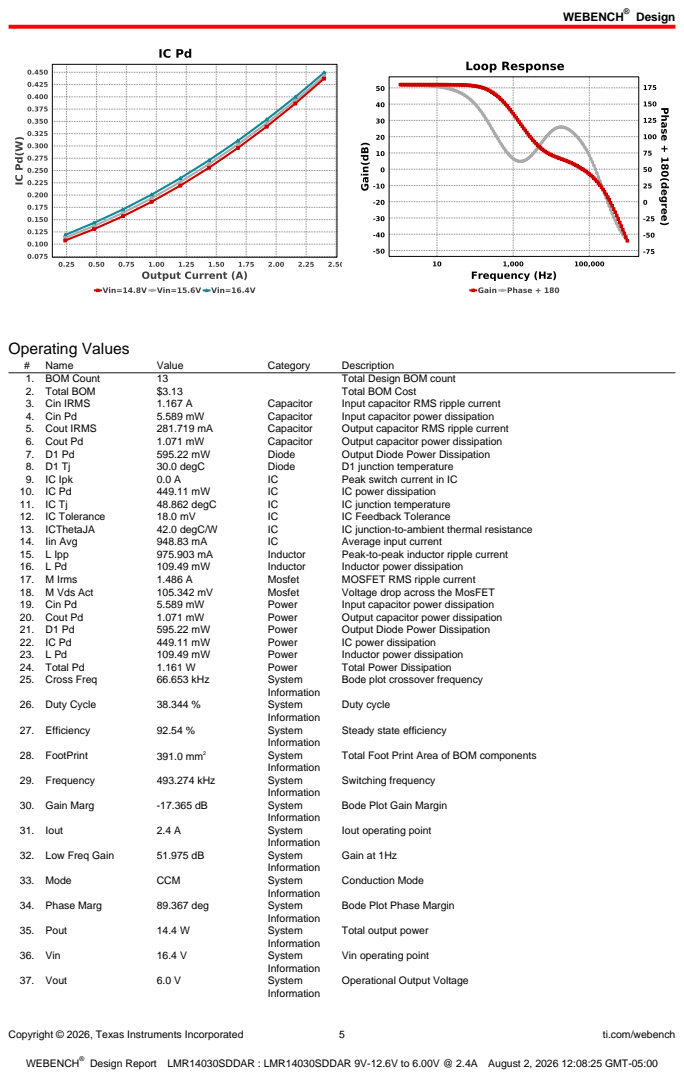
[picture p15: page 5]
Copyright © 2026, Texas Instruments Incorporated; ti.com/webench; Operating Values; Name; Value; Category; Description; 1. BOM Count; Total Design BOM count; 2. Total BOM; Total BOM Cost; 3. Cin IRMS; Capacitor; Input capacitor RMS ripple current; 4. Cin Pd; Input capacitor power dissipation; 5. Cout IRMS; Output capacitor RMS ripple current; 6. Cout Pd; Output capacitor power dissipation; Diode; Output Diode Power Dissipation; 30.0 degC; D1 junction temperature; 9. IC Ipk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

Bode plot crossover frequency

Steady state efficiency

Total Foot Print Area of BOM components

Bode Plot Gain Margin

Iout operating point

Bode Plot Phase Margin

Total output power

Vin operating point

Operational Output Voltage

Copyright © 2026, Texas Instruments Incorporated | 6 | ti.com/webench
# | Name | Value | Category | Description

38. Vout Actual | 6.0 V | System
| | | Information | Vout Actual calculated based on selected voltage divider resistors
39. Vout Tolerance | 4.21 % | System
| | | Information | Vout Tolerance based on IC Tolerance (no load) and voltage divider resistors if applicable
40. Vout p-p | 13.261 mV | System
| | | Information | Peak-to-peak output ripple voltage

## Design Inputs

Name | Value | Description
Iout | 2.4 | Maximum Output Current
SoftStart | 2.0 ms | Soft Start Time (ms)
VinMax | 16.4 | Maximum input voltage
VinMin | 14.8 | Minimum input voltage
Vout | 6.0 | Output Voltage
| base_pn | | LMR14030S | Base Product Number
source | DC | Input Source Type
Ta | 30.0 | Ambient temperature
UserFsw | 500.0 k | Customer Selected Frequency


Copyright © 2026, Texas Instruments Incorporated | 7 | ti.com/webench

## Assembly

## Component Testing

Some published data on components in datasheets such as Capacitor ESR and Inductor DC resistance is based on conservative values that will guarantee that the components always exceed the specification. For design purposes it is usually better to work with typical values. Since this data is not always available it is a good practice to measure the Capacitance and ESR values of Cin and Cout, and the inductance and DC resistance of L1 before assembly of the board. Any large discrepancies in values should be electrically simulated in WEBENCH to check for instabilities and thermally simulated in WebTHERM to make sure critical temperatures are not exceeded.

## Soldering Component to Board

If board assembly is done in house it is best to tack down one terminal of a component on the board then solder the other terminal. For surface mount parts with large tabs, such as the DPAK, the tab on the back of the package should be pre-tinned with solder, then tacked into place by one of the pins. To solder the tab town to the board place the iron down on the board while resting against the tab, heating both surfaces simultaneously. Apply light pressure to the top of the plastic case until the solder flows around the part and the part is flush with the PCB. If the solder is not flowing around the board you may need a higher wattage iron (generally 25W to 30W is enough).
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

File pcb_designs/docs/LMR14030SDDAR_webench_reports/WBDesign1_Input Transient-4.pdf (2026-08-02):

## WEBENCH ® Design Report

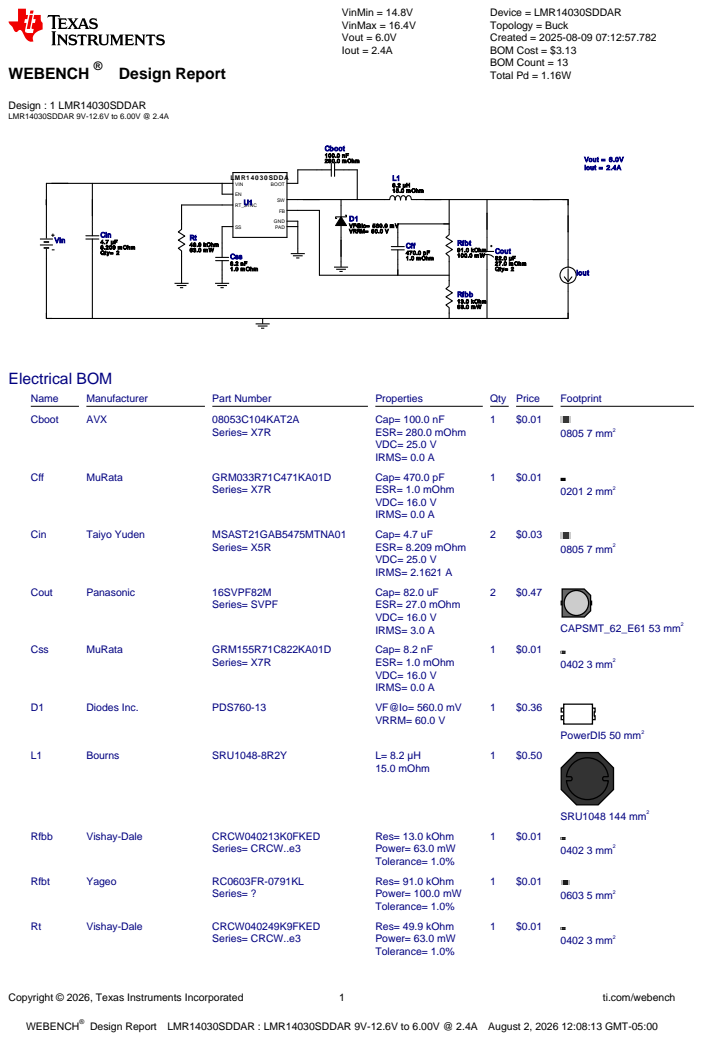
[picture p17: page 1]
Copyright © 2026, Texas Instruments Incorporated; ti.com/webench; WEBENCH®; Design : 1 LMR14030SDDAR LMR14030SDDAR 9V-12.6V to 6.00V @ 2.4A; VinMin = 14.8V VinMax = 16.4V Vout = 6.0V Iout = 2.4A; Device = LMR14030SDDAR Topology = Buck Created = 2025-08-09 07:12:57.782 BOM Cost = $3.13 BOM Count = 13 Total Pd = 1.16W; Css 8.2 nF 1.0 m Ohm; Vout = 6.0V Iout = 2.4A; Rfbb 13.0 kOhm 63.0 m W; Cout 82.0 µF 27.0 m Ohm Qty= 2; L1 8.2 µH 15.0 m Ohm; Cboot 100.0 nF 280.0 m Ohm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

Design Report LMR14030SDDAR : LMR14030SDDAR 9V-12.6V to 6.00V @ 2.4A August 2, 2026 12:08:13 GMT-05:00

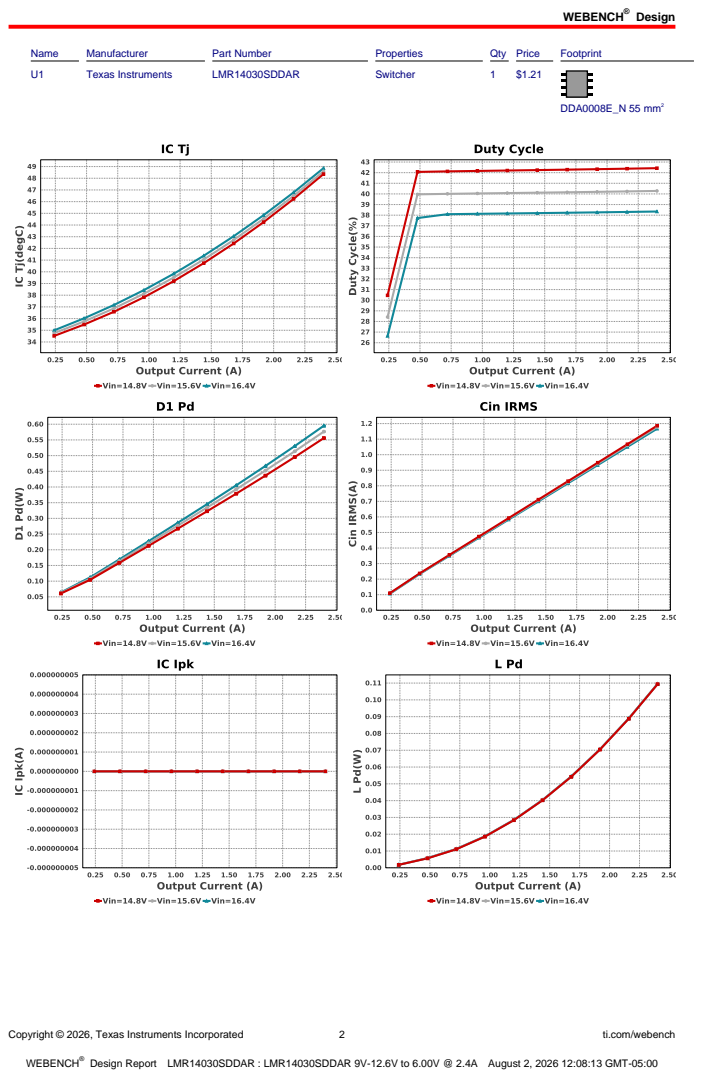
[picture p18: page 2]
Design; Copyright © 2026, Texas Instruments Incorporated; ti.com/webench; Name; Manufacturer; Part Number; Properties; Qty Price; Footprint; Texas Instruments; LMR14030SDDAR; Switcher; DDA0008E_N 55 mm²

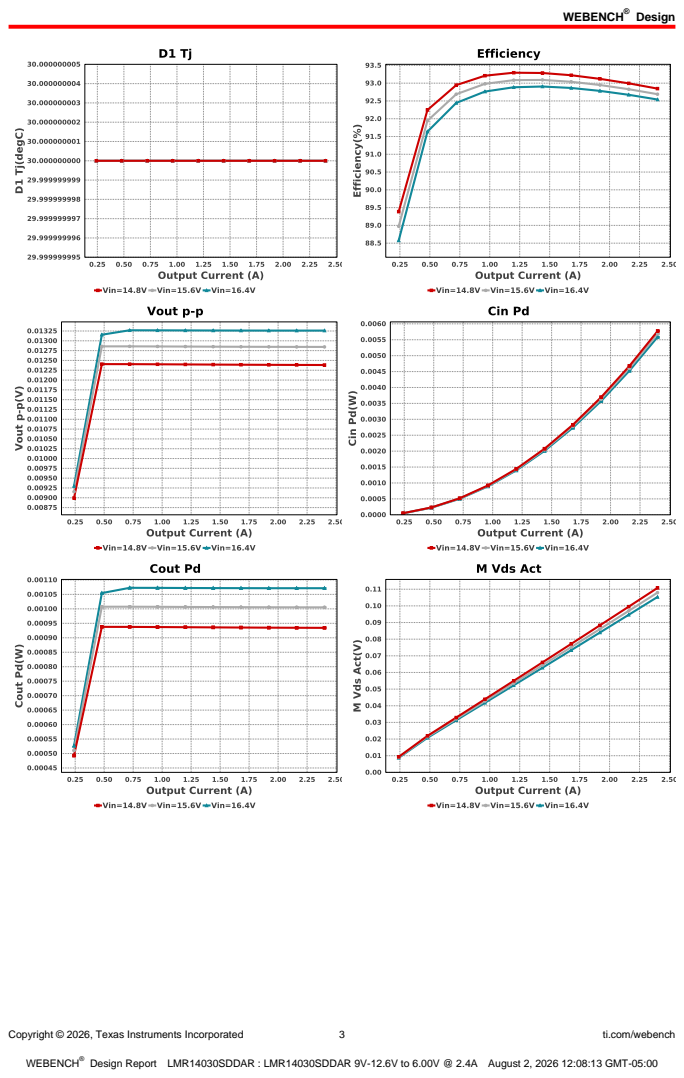
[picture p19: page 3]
Copyright © 2026, Texas Instruments Incorporated; ti.com/webench

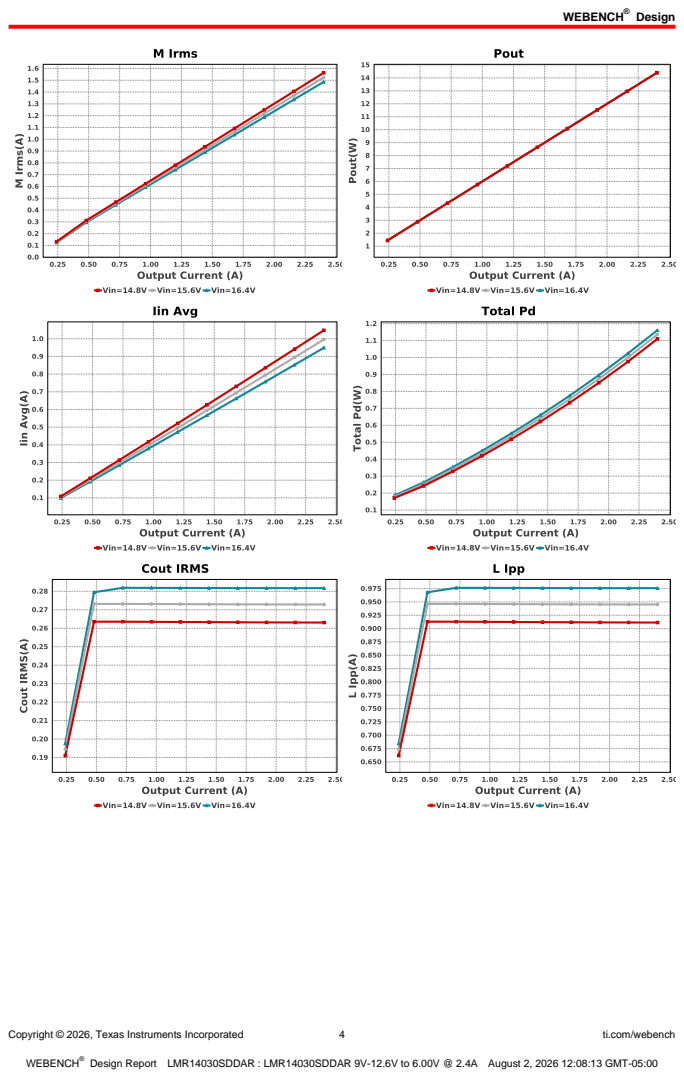
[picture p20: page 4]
Copyright © 2026, Texas Instruments Incorporated; ti.com/webench

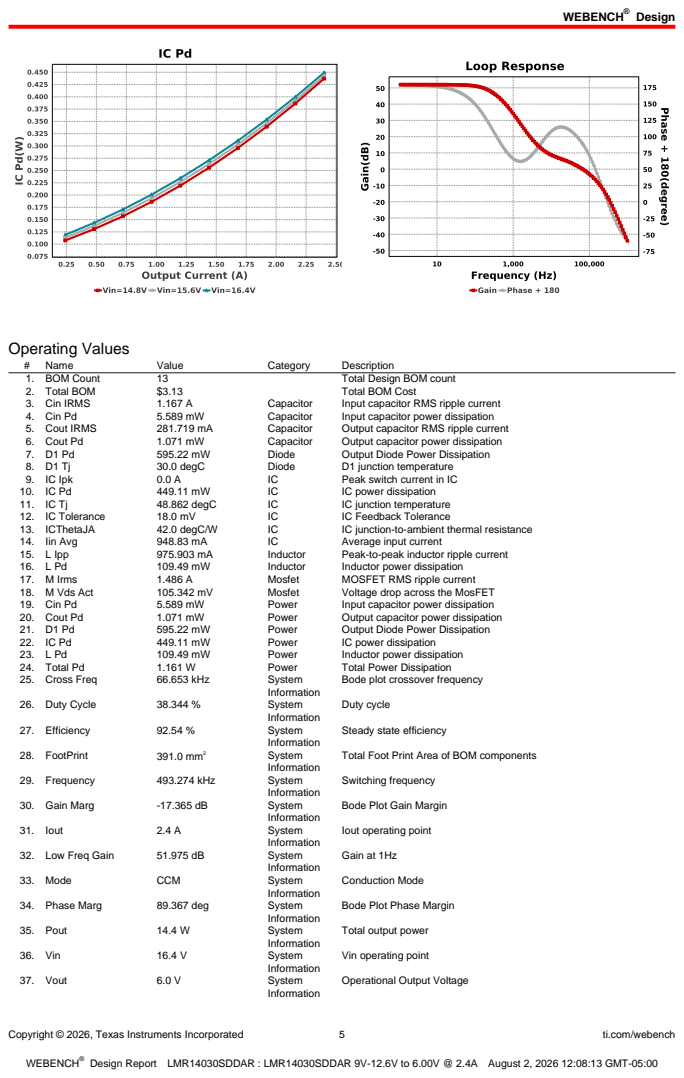
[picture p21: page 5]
Copyright © 2026, Texas Instruments Incorporated; ti.com/webench; Operating Values; Name; Value; Category; Description; 1. BOM Count; Total Design BOM count; 2. Total BOM; Total BOM Cost; 3. Cin IRMS; Capacitor; Input capacitor RMS ripple current; 4. Cin Pd; Input capacitor power dissipation; 5. Cout IRMS; Output capacitor RMS ripple current; 6. Cout Pd; Output capacitor power dissipation; Diode; Output Diode Power Dissipation; 30.0 degC; D1 junction temperature; 9. IC Ipk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

Bode plot crossover frequency

Steady state efficiency

Total Foot Print Area of BOM components

Bode Plot Gain Margin

Iout operating point

Bode Plot Phase Margin

Total output power

Vin operating point

Operational Output Voltage

Copyright © 2026, Texas Instruments Incorporated | 6 | ti.com/webench
# | Name | Value | Category | Description

38. Vout Actual | 6.0 V | System
| | | Information | Vout Actual calculated based on selected voltage divider resistors
39. Vout Tolerance | 4.21 % | System
| | | Information | Vout Tolerance based on IC Tolerance (no load) and voltage divider resistors if applicable
40. Vout p-p | 13.261 mV | System
| | | Information | Peak-to-peak output ripple voltage

## Design Inputs

Name | Value | Description
Iout | 2.4 | Maximum Output Current
SoftStart | 2.0 ms | Soft Start Time (ms)
VinMax | 16.4 | Maximum input voltage
VinMin | 14.8 | Minimum input voltage
Vout | 6.0 | Output Voltage
| base_pn | | LMR14030S | Base Product Number
source | DC | Input Source Type
Ta | 30.0 | Ambient temperature
UserFsw | 500.0 k | Customer Selected Frequency


Copyright © 2026, Texas Instruments Incorporated | 7 | ti.com/webench

## Assembly

## Component Testing

Some published data on components in datasheets such as Capacitor ESR and Inductor DC resistance is based on conservative values that will guarantee that the components always exceed the specification. For design purposes it is usually better to work with typical values. Since this data is not always available it is a good practice to measure the Capacitance and ESR values of Cin and Cout, and the inductance and DC resistance of L1 before assembly of the board. Any large discrepancies in values should be electrically simulated in WEBENCH to check for instabilities and thermally simulated in WebTHERM to make sure critical temperatures are not exceeded.

## Soldering Component to Board

If board assembly is done in house it is best to tack down one terminal of a component on the board then solder the other terminal. For surface mount parts with large tabs, such as the DPAK, the tab on the back of the package should be pre-tinned with solder, then tacked into place by one of the pins. To solder the tab town to the board place the iron down on the board while resting against the tab, heating both surfaces simultaneously. Apply light pressure to the top of the plastic case until the solder flows around the part and the part is flush with the PCB. If the solder is not flowing around the board you may need a higher wattage iron (generally 25W to 30W is enough).
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

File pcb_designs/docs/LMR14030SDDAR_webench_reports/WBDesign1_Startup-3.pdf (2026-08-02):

## WEBENCH ® Design Report

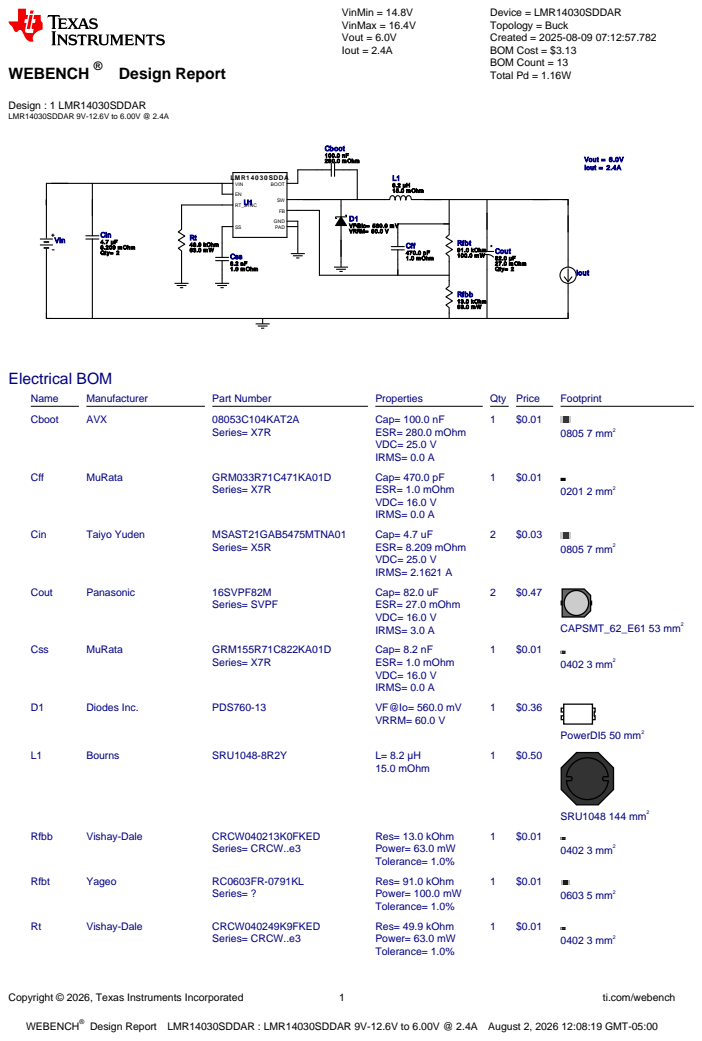
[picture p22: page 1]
Copyright © 2026, Texas Instruments Incorporated; ti.com/webench; WEBENCH®; Design : 1 LMR14030SDDAR LMR14030SDDAR 9V-12.6V to 6.00V @ 2.4A; VinMin = 14.8V VinMax = 16.4V Vout = 6.0V Iout = 2.4A; Device = LMR14030SDDAR Topology = Buck Created = 2025-08-09 07:12:57.782 BOM Cost = $3.13 BOM Count = 13 Total Pd = 1.16W; Css 8.2 nF 1.0 m Ohm; Vout = 6.0V Iout = 2.4A; Rfbb 13.0 kOhm 63.0 m W; Cout 82.0 µF 27.0 m Ohm Qty= 2; L1 8.2 µH 15.0 m Ohm; Cboot 100.0 nF 280.0 m Ohm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

Design Report LMR14030SDDAR : LMR14030SDDAR 9V-12.6V to 6.00V @ 2.4A August 2, 2026 12:08:19 GMT-05:00

Design; Copyright © 2026, Texas Instruments Incorporated; ti.com/webench; Name; Manufacturer; Part Number; Properties; Qty Price; Footprint; Texas Instruments; LMR14030SDDAR; Switcher; DDA0008E_N 55 mm²

Copyright © 2026, Texas Instruments Incorporated; ti.com/webench

Copyright © 2026, Texas Instruments Incorporated; ti.com/webench

Copyright © 2026, Texas Instruments Incorporated; ti.com/webench; Operating Values; Name; Value; Category; Description; 1. BOM Count; Total Design BOM count; 2. Total BOM; Total BOM Cost; 3. Cin IRMS; Capacitor; Input capacitor RMS ripple current; 4. Cin Pd; Input capacitor power dissipation; 5. Cout IRMS; Output capacitor RMS ripple current; 6. Cout Pd; Output capacitor power dissipation; Diode; Output Diode Power Dissipation; 30.0 degC; D1 junction temperature; 9. IC Ipk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

Bode plot crossover frequency

Steady state efficiency

Total Foot Print Area of BOM components

Bode Plot Gain Margin

Iout operating point

Bode Plot Phase Margin

Total output power

Vin operating point

Operational Output Voltage

Copyright © 2026, Texas Instruments Incorporated | 6 | ti.com/webench
# | Name | Value | Category | Description

38. Vout Actual | 6.0 V | System
| | | Information | Vout Actual calculated based on selected voltage divider resistors
39. Vout Tolerance | 4.21 % | System
| | | Information | Vout Tolerance based on IC Tolerance (no load) and voltage divider resistors if applicable
40. Vout p-p | 13.261 mV | System
| | | Information | Peak-to-peak output ripple voltage

## Design Inputs

Name | Value | Description
Iout | 2.4 | Maximum Output Current
SoftStart | 2.0 ms | Soft Start Time (ms)
VinMax | 16.4 | Maximum input voltage
VinMin | 14.8 | Minimum input voltage
Vout | 6.0 | Output Voltage
| base_pn | | LMR14030S | Base Product Number
source | DC | Input Source Type
Ta | 30.0 | Ambient temperature
UserFsw | 500.0 k | Customer Selected Frequency


Copyright © 2026, Texas Instruments Incorporated | 7 | ti.com/webench

## Assembly

## Component Testing

Some published data on components in datasheets such as Capacitor ESR and Inductor DC resistance is based on conservative values that will guarantee that the components always exceed the specification. For design purposes it is usually better to work with typical values. Since this data is not always available it is a good practice to measure the Capacitance and ESR values of Cin and Cout, and the inductance and DC resistance of L1 before assembly of the board. Any large discrepancies in values should be electrically simulated in WEBENCH to check for instabilities and thermally simulated in WebTHERM to make sure critical temperatures are not exceeded.

## Soldering Component to Board

If board assembly is done in house it is best to tack down one terminal of a component on the board then solder the other terminal. For surface mount parts with large tabs, such as the DPAK, the tab on the back of the package should be pre-tinned with solder, then tacked into place by one of the pins. To solder the tab town to the board place the iron down on the board while resting against the tab, heating both surfaces simultaneously. Apply light pressure to the top of the plastic case until the solder flows around the part and the part is flush with the PCB. If the solder is not flowing around the board you may need a higher wattage iron (generally 25W to 30W is enough).
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

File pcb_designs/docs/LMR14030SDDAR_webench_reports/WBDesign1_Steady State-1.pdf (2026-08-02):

## WEBENCH ® Design Report

Copyright © 2026, Texas Instruments Incorporated; ti.com/webench; WEBENCH®; Design : 1 LMR14030SDDAR LMR14030SDDAR 9V-12.6V to 6.00V @ 2.4A; VinMin = 14.8V VinMax = 16.4V Vout = 6.0V Iout = 2.4A; Device = LMR14030SDDAR Topology = Buck Created = 2025-08-09 07:12:57.782 BOM Cost = $3.13 BOM Count = 13 Total Pd = 1.16W; Css 8.2 nF 1.0 m Ohm; Vout = 6.0V Iout = 2.4A; Rfbb 13.0 kOhm 63.0 m W; Cout 82.0 µF 27.0 m Ohm Qty= 2; L1 8.2 µH 15.0 m Ohm; Cboot 100.0 nF 280.0 m Ohm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

Design Report LMR14030SDDAR : LMR14030SDDAR 9V-12.6V to 6.00V @ 2.4A August 2, 2026 12:08:31 GMT-05:00

Design; Copyright © 2026, Texas Instruments Incorporated; ti.com/webench; Name; Manufacturer; Part Number; Properties; Qty Price; Footprint; Texas Instruments; LMR14030SDDAR; Switcher; DDA0008E_N 55 mm²

Copyright © 2026, Texas Instruments Incorporated; ti.com/webench

Copyright © 2026, Texas Instruments Incorporated; ti.com/webench

Copyright © 2026, Texas Instruments Incorporated; ti.com/webench; Operating Values; Name; Value; Category; Description; 1. BOM Count; Total Design BOM count; 2. Total BOM; Total BOM Cost; 3. Cin IRMS; Capacitor; Input capacitor RMS ripple current; 4. Cin Pd; Input capacitor power dissipation; 5. Cout IRMS; Output capacitor RMS ripple current; 6. Cout Pd; Output capacitor power dissipation; Diode; Output Diode Power Dissipation; 30.0 degC; D1 junction temperature; 9. IC Ipk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

Bode plot crossover frequency

Steady state efficiency

Total Foot Print Area of BOM components

Bode Plot Gain Margin

Iout operating point

Bode Plot Phase Margin

Total output power

Vin operating point

Operational Output Voltage

Copyright © 2026, Texas Instruments Incorporated | 6 | ti.com/webench
# | Name | Value | Category | Description

38. Vout Actual | 6.0 V | System
| | | Information | Vout Actual calculated based on selected voltage divider resistors
39. Vout Tolerance | 4.21 % | System
| | | Information | Vout Tolerance based on IC Tolerance (no load) and voltage divider resistors if applicable
40. Vout p-p | 13.261 mV | System
| | | Information | Peak-to-peak output ripple voltage

## Design Inputs

Name | Value | Description
Iout | 2.4 | Maximum Output Current
SoftStart | 2.0 ms | Soft Start Time (ms)
VinMax | 16.4 | Maximum input voltage
VinMin | 14.8 | Minimum input voltage
Vout | 6.0 | Output Voltage
| base_pn | | LMR14030S | Base Product Number
source | DC | Input Source Type
Ta | 30.0 | Ambient temperature
UserFsw | 500.0 k | Customer Selected Frequency


Copyright © 2026, Texas Instruments Incorporated | 7 | ti.com/webench

## Assembly

## Component Testing

Some published data on components in datasheets such as Capacitor ESR and Inductor DC resistance is based on conservative values that will guarantee that the components always exceed the specification. For design purposes it is usually better to work with typical values. Since this data is not always available it is a good practice to measure the Capacitance and ESR values of Cin and Cout, and the inductance and DC resistance of L1 before assembly of the board. Any large discrepancies in values should be electrically simulated in WEBENCH to check for instabilities and thermally simulated in WebTHERM to make sure critical temperatures are not exceeded.

## Soldering Component to Board

If board assembly is done in house it is best to tack down one terminal of a component on the board then solder the other terminal. For surface mount parts with large tabs, such as the DPAK, the tab on the back of the package should be pre-tinned with solder, then tacked into place by one of the pins. To solder the tab town to the board place the iron down on the board while resting against the tab, heating both surfaces simultaneously. Apply light pressure to the top of the plastic case until the solder flows around the part and the part is flush with the PCB. If the solder is not flowing around the board you may need a higher wattage iron (generally 25W to 30W is enough).
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

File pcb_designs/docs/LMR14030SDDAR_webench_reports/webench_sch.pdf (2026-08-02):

8/2/26, 10:37 PM | WBDesign1.svg

Css 8.2nF 1mOhm; Rfbb 1133kkOOhhmm; Cout 82uF 2277mmOOhhmm Qty=2; 8.2uH 1155mmOOhhmm; Cboot; 100nF 228800mmOOhhmm; Cin 4.7uF 88..220099mmOOhhmm Qty=2; LMR14030SDDA; VIN; BOOT; RT_SYNC; GND; PAD; 4499..99kkOOhhmm; Cff; 470pF 1mOhm; Rfbt 9911kkOOhhmm; Iout; Vin; file:///C:/Users/Thevinu Fernando/Downloads/WBDesign1.svg

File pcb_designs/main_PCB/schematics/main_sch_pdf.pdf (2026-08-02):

# USB 2.0 USB-C

# OLED DISPLAY( I2C )


POWER SELECTION( USB or EXT or DEBUG )

MOTORS & ENCODERS( LM & RM )

1

2


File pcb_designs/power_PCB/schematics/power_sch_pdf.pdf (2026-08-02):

# BATTERY POWER SUPPLY

# VBAT to +3V3 CONVERTION


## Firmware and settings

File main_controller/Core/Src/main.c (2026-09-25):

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
/* Includes ------------------------------------------------------------------*/
#include "main.h"

/* USER CODE BEGIN Includes */
#include "DRV8833.h"
#include "dwt_timer.h"
#include "straightline_controller.h"
#include "turn_controller.h"
#include "test_harness.h"
#include "tof_sensors.h"
/* USER CODE END Includes */

/* USER CODE BEGIN PD */

/* Test selection, test parameters, and all on-target test routines live in
 * test_harness.h / test_harness.c, not here. main.c only brings up hardware
 * and hands control to TestHarness_RunCycle(). */

/* USER CODE END PD */

I2C_HandleTypeDef hi2c1;

SPI_HandleTypeDef hspi1;

TIM_HandleTypeDef htim1;
TIM_HandleTypeDef htim2;
TIM_HandleTypeDef htim3;

/* USER CODE BEGIN PV */

/* All tm_* live-watch telemetry globals are defined in test_harness.c and
 * declared extern in test_harness.h. Add their names to the "liveWatch"
 * expressions list in .vscode/launch.json to observe them while the robot
 * runs. */

/* USER CODE END PV */

void SystemClock_Config(void);
static void MX_GPIO_Init(void);
static void MX_TIM1_Init(void);
static void MX_TIM2_Init(void);
static void MX_TIM3_Init(void);
static void MX_SPI1_Init(void);
static void MX_I2C1_Init(void);
/* USER CODE BEGIN 0 */

/* All test routines (LED_Blink, Telemetry_Capture, Test_* etc.) moved to
 * test_harness.c. main.c only calls TestHarness_RunCycle() from the loop
 * below. */

/* USER CODE END 0 */

/**
  * @brief  The application entry point.
  * @retval int
  */
int main(void)
{

  /* MCU Configuration--------------------------------------------------------*/

  /* Reset of all peripherals, Initializes the Flash interface and the Systick. */
  HAL_Init();

  /* Configure the system clock */
  SystemClock_Config();

  /* Initialize all configured peripherals */
  MX_GPIO_Init();
  MX_TIM1_Init();
  MX_TIM2_Init();
  MX_TIM3_Init();
  MX_SPI1_Init();
  MX_I2C1_Init();
  /* USER CODE BEGIN 2 */

  /* Start the quadrature encoder interfaces. CubeMX configures the timers but
   * does not start them, so without this the counters never move. */
  HAL_TIM_Encoder_Start(&htim1, TIM_CHANNEL_ALL);   /* right encoder */
  HAL_TIM_Encoder_Start(&htim2, TIM_CHANNEL_ALL);   /* left encoder  */

  /* Start the four motor PWM channels (2 per motor, IN/IN drive mode). */
  HAL_TIM_PWM_Start(&htim3, TIM_CHANNEL_1);   /* RM_PWM_INA */
  HAL_TIM_PWM_Start(&htim3, TIM_CHANNEL_2);   /* RM_PWM_INB */
  HAL_TIM_PWM_Start(&htim3, TIM_CHANNEL_3);   /* LM_PWM_INA */
  HAL_TIM_PWM_Start(&htim3, TIM_CHANNEL_4);   /* LM_PWM_INB */

  /* Make sure nothing is driven until a test asks for it. */
  Motor_Brake();

  /* Microsecond timebase for the EKF prediction step. Must come before any
   * controller init, since TurnController_Init() times its gyro calibration
   * with it. */
  DWT_Timer_Init();

  /* CubeMX drives IMU_NCS LOW in MX_GPIO_Init(), but SPI chip select must
   * IDLE HIGH or the first transaction is framed wrong. Deassert it before
   * talking to the IMU. */
  HAL_GPIO_WritePin(IMU_NCS_GPIO_Port, IMU_NCS_Pin, GPIO_PIN_SET);
  HAL_Delay(50);

  /* Bring up both controllers. Each pulls its gains from control_config.h.
   * Both call Encoders_Init() and MotorDriver_Enable() internally, which is
   * idempotent, so initialising both here is safe.
   *
   * TurnController_Init() also brings up the IMU and runs the stationary gyro
   * bias calibration, so THE ROBOT MUST BE STILL AND LEVEL AT POWER-ON. */
  StraightlineController_Init();
  tm_imu_ok = TurnController_Init();

  /* Startup indication.
   *   3 slow blinks           = IMU up, bias calibrated, fusion active
   *   3 slow THEN 6 fast      = IMU up but bias calibration was REJECTED.
   *                             Turns still run, but on an unestimated gyro
   *                             bias. Read turn_bias_cal_status for the
   *                             reason (moved during calibration vs. a
   *                             failed gyro read).
   *   6 fast blinks           = IMU not found, running encoder-only */
  if (tm_imu_ok) {
    LED_Blink(3, 300, 300);

    if (!TurnController_IsBiasCalibrated()) {
      LED_Blink(6, 80, 80);
    }
  }
  else {
    LED_Blink(6, 80, 80);
  }

  tm_gyro_bias_dps = TurnController_GetGyroBiasDps();

  /* Bring up the TCA9548A mux and the three VL53L0X ranging sensors.
   *
   * This takes noticeably longer than the other peripherals: each sensor runs
   * reference SPAD management and VHV/phase calibration, so budget ~50-100 ms
   * per sensor.
   *
   * Like the IMU, a failure here is NOT fatal. Nothing in the motion
   * controllers consumes range data yet, so a dead sensor must not stop the
   * robot from driving. 2 fast blinks flags it; tm_tof_ready says which
   * sensors actually came up. */
  if (ToF_Init() != TOF_OK) {
    LED_Blink(2, 80, 80);
  }

  TestHarness_CaptureToFReady();

  /* Settling delay so the robot is not already moving when you take your
   * hand off it. */
  HAL_Delay(2000);

  /* USER CODE END 2 */

  /* Infinite loop */
  /* USER CODE BEGIN WHILE */
  while (1)
  {
    /* USER CODE END WHILE */

    /* USER CODE BEGIN 3 */

    /* Runs whichever test ACTIVE_TEST selects (test_harness.h), including
     * its cycle pause. See test_harness.c for the dispatch and routines. */
    TestHarness_RunCycle();
  }
  /* USER CODE END 3 */
}

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


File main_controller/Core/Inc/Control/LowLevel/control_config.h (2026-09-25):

#ifndef CONTROL_CONFIG_H
#define CONTROL_CONFIG_H

/*
 * ============================================================================
 *                          PID TUNING INTERFACE
 * ============================================================================
 *
 * All tunable gains for the low-level controllers live here. Edit the values
 * below, rebuild, and flash. Straightline and turn controllers are tuned
 * independently.
 *
 * Units:
 *   - Distance PID  : setpoint/measurement in cm, output in motor speed units
 *   - Straight PID  : setpoint/measurement in raw encoder ticks (left - right),
 *                     output is a differential speed correction
 *   - Turn PID      : setpoint/measurement in cm of wheel arc, output in motor
 *                     speed units
 *
 * Motor speed units are 0..255 (mapped to 0..MOTOR_PWM_MAX in the driver).
 *
 * ---------------------------------------------------------------------------
 * SUGGESTED TUNING ORDER
 * ---------------------------------------------------------------------------
 *  1. Set every Ki and Kd to 0.
 *  2. Raise Kp until the robot reaches the target with a small overshoot.
 *  3. Add Kd to damp the overshoot.
 *  4. Add a small Ki only if it consistently stops short of the target.
 *
 * Tune STRAIGHT_DIST_* first (drive straight, ignore heading), then
 * STRAIGHT_HEADING_* (heading hold), then the turn gains separately.
 * ============================================================================
 */

/* ------------------------- Common PID settings --------------------------- */

/* Control loop sample time in seconds (10 ms = 100 Hz) */
#define CONTROL_SAMPLE_TIME_S 0.010f

/* Derivative low-pass filter time constant in seconds.
 * Rule of thumb: keep it a few times larger than the sample time.
 * Must be > 0 or the derivative term is unfiltered.
 *
 * Held at 0.010 (= T), knowingly violating the rule above. 0.030 was tried
 * and REVERTED: a 5-move TEST_TURN_LEFT_90 run went 3/5 -> 0/5, every move
 * timing out 3.6-5.9 deg short. Only tau changed between those two runs.
 *
 * The theory it was testing turned out to be wrong. The robot was NOT in a
 * stick-slip limit cycle driven by derivative spikes; it was stalling dead
 * and unable to restart (turn_gyro_rate_dps ~0.15 with turn_basespeed at
 * 65.4, i.e. commanded hard and not moving). Raising tau makes the
 * derivative LAG, which kept braking torque applied for ~30 ms after motion
 * had already ceased -- helping to seat the wheel in the stall rather than
 * preventing it. See TURN_INT_LIMIT for the actual fix.
 *
 * Worth revisiting only if a derivative term is ever run at a Kd high enough
 * that transient rejection matters more than phase lag. Note tau does NOT
 * change steady-state damping (the term settles to -Kd * d(measurement)/dt
 * regardless), so raising it only ever costs phase, never authority. */
#define CONTROL_DERIV_TAU_S 0.010f

/* Maximum motor speed command the controllers may produce (0..255). */
#define CONTROL_MAX_SPEED 200.0f

/* Minimum speed magnitude that still overcomes gearbox stiction.
 * Commands below this (but non-zero) are boosted up to it, so the robot
 * does not stall just short of the target. Set to 0.0f to disable.
 *
 * Raised from 35 -> 45: a 5-cycle TEST_TURN_LEFT_90 run at 35 completed 4/5
 * turns (undershooting 0.77-0.93 deg each time) but stalled on the 5th --
 * motor audibly running, wheel not turning, stuck until CONTROL_MOVE_TIMEOUT_MS
 * fired at 2.04 deg short. That pattern (consistent small undershoot,
 * occasional stall needing the same nudge) points to 35 sitting right at this
 * motor's real low-PWM breakaway torque rather than a loose/slipping
 * coupling. TURN_KI masks this some of the time by winding up until it
 * breaks through, but isn't a guaranteed fix, hence raising the floor itself.
 * Retest both turn and straight-line moves after changing this -- it is
 * shared by both controllers. */
#define CONTROL_MIN_MOVE_SPEED 45.0f

/* ====================== STRAIGHTLINE: DISTANCE PID ======================= */
/* Drives average travelled distance (cm) to the target distance.            */

#define STRAIGHT_DIST_KP 20.0f
#define STRAIGHT_DIST_KI 0.0f
#define STRAIGHT_DIST_KD 0.0f

/* Integrator clamp, in motor speed units */
#define STRAIGHT_DIST_INT_LIMIT 50.0f

/* ====================== STRAIGHTLINE: HEADING PID ======================== */
/* Holds (left_count - right_count) at zero so the robot tracks straight.    */
/* Measurement is in RAW ENCODER TICKS, so these gains are small.            */

#define STRAIGHT_HEADING_KP 0.5f
#define STRAIGHT_HEADING_KI 0.025f
#define STRAIGHT_HEADING_KD 0.00f

/* Steering authority clamp, in motor speed units */
#define STRAIGHT_HEADING_LIMIT 80.0f
#define STRAIGHT_HEADING_INT_LIMIT 20.0f

/* ====================== ROBOT GEOMETRY / CALIBRATION ===================== */
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

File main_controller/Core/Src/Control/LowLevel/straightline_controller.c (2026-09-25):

#include "straightline_controller.h"
#include "yaw_estimator.h"
#include "turn_controller.h"
#include "wall_follow.h"
#include "tof_sensors.h"
#include "motion_profile.h"

static Controller_t controller;

static uint32_t pid_last_time = 0;
static uint32_t move_start_time = 0;
static float pid_sample_time_s;
static uint16_t settle_counter = 0;

//Debugging
int32_t left_count;
int32_t right_count;
int16_t left_delta_count;
int16_t right_delta_count;
float left_distance;
float right_distance;
float basespeed;
float steering;

//Initialse the controller using the gains from control_config.h
void StraightlineController_Init(void) {

    //Initialise dependencies
    Encoders_Init();
    MotorDriver_Enable();

    //Distance PID: average travelled distance (cm) -> base speed
    controller.distance_pid.Kp        = STRAIGHT_DIST_KP;
    controller.distance_pid.Ki        = STRAIGHT_DIST_KI;
    controller.distance_pid.Kd        = STRAIGHT_DIST_KD;
    controller.distance_pid.tau       = CONTROL_DERIV_TAU_S;
    controller.distance_pid.T         = CONTROL_SAMPLE_TIME_S;
    controller.distance_pid.limMin    = -CONTROL_MAX_SPEED;
    controller.distance_pid.limMax    =  CONTROL_MAX_SPEED;
    controller.distance_pid.limMinInt = -STRAIGHT_DIST_INT_LIMIT;
    controller.distance_pid.limMaxInt =  STRAIGHT_DIST_INT_LIMIT;

    //Heading PID: (left - right) encoder ticks -> steering correction
    controller.straight_pid.Kp        = STRAIGHT_HEADING_KP;
    controller.straight_pid.Ki        = STRAIGHT_HEADING_KI;
    controller.straight_pid.Kd        = STRAIGHT_HEADING_KD;
    controller.straight_pid.tau       = CONTROL_DERIV_TAU_S;
    controller.straight_pid.T         = CONTROL_SAMPLE_TIME_S;
    controller.straight_pid.limMin    = -STRAIGHT_HEADING_LIMIT;
    controller.straight_pid.limMax    =  STRAIGHT_HEADING_LIMIT;
    controller.straight_pid.limMinInt = -STRAIGHT_HEADING_INT_LIMIT;
    controller.straight_pid.limMaxInt =  STRAIGHT_HEADING_INT_LIMIT;

    pid_sample_time_s = controller.distance_pid.T;

    //Initialise PID instances
    PIDController_Init(&controller.straight_pid);
    PIDController_Init(&controller.distance_pid);

    controller.state = STRAIGHTLINE_IDLE;
}

//Helper function to reset PID values
static void resetPID(void) {

    PIDController_Init(&controller.straight_pid);
    PIDController_Init(&controller.distance_pid);

    pid_last_time = 0;
    settle_counter = 0;
}

//Apply the stiction floor without changing the sign of the request
static float applyMinSpeed(float speed) {

    if (CONTROL_MIN_MOVE_SPEED <= 0.0f) return speed;

    if (speed > 0.0f && speed < CONTROL_MIN_MOVE_SPEED) {
        return CONTROL_MIN_MOVE_SPEED;
    }
    if (speed < 0.0f && speed > -CONTROL_MIN_MOVE_SPEED) {
        return -CONTROL_MIN_MOVE_SPEED;
    }

    return speed;
}

//Helper function to update PID controllers
static void updatePID(float target_distance, float direction) {

    //Check if controller is running
    if (controller.state != STRAIGHTLINE_RUNNING) {
        return;
    }

    uint32_t current_time = HAL_GetTick();

    //Safety timeout so a stalled robot cannot spin here forever
    if (current_time - move_start_time >= CONTROL_MOVE_TIMEOUT_MS) {

        controller.state = STRAIGHTLINE_TIMEOUT;
        Motor_Brake();
        return;
    }

    if (current_time - pid_last_time >= (uint32_t)(pid_sample_time_s * 1000.0f)) {

        //Update the last time
        pid_last_time = current_time;

        // Update encoder readings
        Encoders_Update();

        //Signed target: negative when reversing
        float signed_target = target_distance * direction;
        float measured = Encoder_getAverageDistance();

        //Check whether target distance is reached, and stay there a few
        //cycles so we do not declare success while coasting through it
        uint8_t within_tolerance =
            (fabsf(measured - signed_target) < DISTANCE_TOLERANCE_CM);

        if (within_tolerance) {

            settle_counter++;

            if (settle_counter >= CONTROL_SETTLE_CYCLES) {

                //Set state to completed
                controller.state = STRAIGHTLINE_COMPLETED;

                //Stop motors completely
                Motor_Brake();

                return;
            }
        }
        else {
            settle_counter = 0;
        }

        //Debugging
        left_count = Encoder_getLeftCount();
        right_count = Encoder_getRightCount();
        left_delta_count = Encoder_getLeftDeltaCount();
        right_delta_count = Encoder_getRightDeltaCount();
        left_distance = Encoder_getLeftDistance();
        right_distance = Encoder_getRightDistance();

        //Distance PID calculations(update)
        basespeed = PIDController_Update(&controller.distance_pid, signed_target, measured);

        //Straightline PID calculations, measurement in raw encoder ticks
        float straightline_measurement = (float)(Encoder_getLeftCount() - Encoder_getRightCount());

        //Straightline PID update
        steering = PIDController_Update(&controller.straight_pid, 0.0f, straightline_measurement);

        /* ---------------- terminal deadband ----------------
         * Once inside the tolerance band, stop driving and brake instead.
         *
         * Without this, applyMinSpeed() below floors the command to
         * +/-CONTROL_MIN_MOVE_SPEED, so the controller kept shoving the robot
         * at full stiction-breaking torque for the whole CONTROL_SETTLE_CYCLES
         * window it was supposed to be settling in. That impulse is far
         * coarser than STRAIGHT_TOLERANCE_CM, so it routinely knocked the
         * robot straight back out of the band it had just reached -- a limit
         * cycle that ends in CONTROL_MOVE_TIMEOUT_MS rather than a completed
         * move.
         *
         * This is the same defect that was removed from turn_controller.c,
         * where it was the single biggest cause of failed moves. The ratio is
         * worse here: 45 speed units against a 0.7 cm band.
         *
         * Both PIDs are still evaluated above, deliberately, so the
         * integrator and the derivative filter stay in step with the real
         * error instead of seeing a discontinuity when driving resumes. */
        if (within_tolerance) {

            basespeed = 0.0f;
            steering  = 0.0f;
            Motor_Brake();

            return;
        }

        //Overcome gearbox stiction near the target
        float commanded = applyMinSpeed(basespeed);

        // Calculate motor speeds. Steering is differential, so it is added to
        // one wheel and subtracted from the other.
        float left_speed = commanded + steering;
        float right_speed = commanded - steering;
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

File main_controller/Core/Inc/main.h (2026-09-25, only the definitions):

#define MCU_LED_Pin GPIO_PIN_3
#define MCU_LED_GPIO_Port GPIOC
#define LM_ENC_CHA_Pin GPIO_PIN_0
#define LM_ENC_CHA_GPIO_Port GPIOA
#define LM_ENC_CHB_Pin GPIO_PIN_1
#define LM_ENC_CHB_GPIO_Port GPIOA
#define IMU_NCS_Pin GPIO_PIN_4
#define IMU_NCS_GPIO_Port GPIOA
#define IMU_SCK_Pin GPIO_PIN_5
#define IMU_SCK_GPIO_Port GPIOA
#define IMU_MISO_Pin GPIO_PIN_6
#define IMU_MISO_GPIO_Port GPIOA
#define IMU_MOSI_Pin GPIO_PIN_7
#define IMU_MOSI_GPIO_Port GPIOA
#define DRV_STBY_Pin GPIO_PIN_14
#define DRV_STBY_GPIO_Port GPIOB
#define RM_PWM_INA_Pin GPIO_PIN_6
#define RM_PWM_INA_GPIO_Port GPIOC
#define RM_PWM_INB_Pin GPIO_PIN_7
#define RM_PWM_INB_GPIO_Port GPIOC
#define LM_PWM_INA_Pin GPIO_PIN_8
#define LM_PWM_INA_GPIO_Port GPIOC
#define LM_PWM_INB_Pin GPIO_PIN_9
#define LM_PWM_INB_GPIO_Port GPIOC
#define RM_ENC_CHA_Pin GPIO_PIN_8
#define RM_ENC_CHA_GPIO_Port GPIOA
#define RM_ENC_CHB_Pin GPIO_PIN_9
#define RM_ENC_CHB_GPIO_Port GPIOA
#define MUX_SCL_Pin GPIO_PIN_6
#define MUX_SCL_GPIO_Port GPIOB
#define MUX_SDA_Pin GPIO_PIN_7
#define MUX_SDA_GPIO_Port GPIOB

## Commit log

2026-07-25 Did some PID tunings
2026-07-30 Integrated the IMU with encoders for turns
2026-08-02 Added PCB design files
    [MM_2.0_pcb.PcbDoc, MM_2.0_power_pcb.PcbDoc, MM_2.0_power_sch.SchDoc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]
2026-08-02 Added the evidence of pcb tests
2026-08-02 Added the README file for pcb_designs
2026-09-09 refactor: update control PID parameters and implement telemetry flight recorder for turn tuning
2026-09-09 refactor: add gyro bias calibration status, improve live-watch debugging, and implement terminal braking for turn control
2026-09-09 feat: add retry logic and increased settle time to gyro bias calibration at startup
2026-09-09 fix: correct Tustin discretization sign error in PID derivative term to ensure proper damping and gain scaling
2026-09-09 feat: update history recording with motion state and tune turn controller PID parameters to resolve stall failure modes.
    [control_config.h, test_harness.c, test_harness.h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]
2026-09-10 Configured the I2C1 for TOF sensors
2026-09-10 Fix issues in straighline motion
    [test_harness.h]
2026-09-10 Added a filter for the noisy TOF readings
2026-09-11 feat: add ToF flight recorder for sensor characterization and update default test harness configuration
2026-09-11 feat: implement stop completion polling for ToF sensors and clean up filtering logic
2026-09-11 feat: implement ToF mode switching test and add telemetry phases to ToFRecord_t
2026-09-11 refactor: extract yaw estimation and sensor fusion logic into a dedicated module
2026-09-11 feat: implement wall following and arena navigation test harness with fused control instrumentation
2026-09-11 fix: enforce maze map boundaries and adjust control parameters for robust navigation
    [control_config.h, navigator.h]
2026-09-11 feat: implement front-wall alignment and reverse-fused movement for backing out of dead ends
    [control_config.h, navigator.h, straightline_controller.c]
2026-09-11 feat: add dual-wall tracking and reverse direction handling to wall follower
    [control_config.h, straightline_controller.c, wall_follow.h]
2026-09-11 refactor: remove reverse wall-following logic and tune control configuration parameters
    [control_config.h, straightline_controller.c]
2026-09-12 refactor: move wall-follow integral outside tilt clamp and add drift telemetry to maze traces
    [control_config.h, navigator.h, straightline_controller.c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]
2026-09-12 fix: increase wall-following max tilt to 10 degrees and update host test assertions
    [control_config.h]
2026-09-12 feat: enable free-running continuous ToF sensors with age gating and dynamic dt in wall follower
2026-09-12 fix: rebuild motion profile instead of translating during front-wall alignment
    [straightline_controller.c]
2026-09-12 refactor: add cell-aware wall following and velocity-continuous front-wall alignment
2026-09-12 feat: add straightline stall abort, integral travel gate, and robot-based alignment checking
    [control_config.h, navigator.h, straightline_controller.c]
2026-09-12 fix: require both position tolerance and settle speed to complete straightline moves
    [control_config.h, straightline_controller.c]
2026-09-12 feat: add non-zero end velocity support to motion profiles and introduce pivot settle time
2026-09-12 refactor: enhance front-wall alignment logic with robust braking estimation, stall checks, and diagnostic reasons
    [cell_motion.c, control_config.h, mms_api.c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]
2026-09-12 feat: expand wall-follow usable distance threshold and add exit lateral error telemetry
    [cell_motion.c, control_config.h, navigator.h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]
2026-09-12 fix : tof vaalues fixed for walls
    [control_config.h]
2026-09-18 Refactor wall following logic to ensure all comparisons use readings; revert setpoint to 52 mm after identifying bias issue. Update angled constants to reflect true readings and improve sensor reliab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
    [control_config.h, test_harness.h, wall_follow.h]
2026-09-18 Implement urgent error handling for wall following; increase tilt slew rate for large lateral errors to improve recovery after pivots.
    [control_config.h]
2026-09-18 Add LED indicators for maze milestones; for goal reach and return to start
2026-09-18 Revert front alignment corroboration gate; it caused alignment failures and drove the robot into walls. Document reasoning and adjustments for future reference.
    [control_config.h, straightline_controller.c]
2026-09-18 Implement front-wall guard logic to prevent collisions; adjust exit conditions for chained segments and ensure proper stopping behavior.
    [cell_motion.c, control_config.h, mms_api.c]
2026-09-18 Enhance stall detection and progress assessment to prevent wedged moves; increase maze trace capacity and add per-wheel travel tracking for better diagnostics.
    [cell_motion.c, control_config.h, navigator.h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]
2026-09-19 Refine urgent-error slew threshold to 8 mm for improved wall-following accuracy; update tests to ensure it arms before clearance is compromised and remains clear of noise.
    [control_config.h]
2026-09-19 Revert handover projection logic to prevent premature stops; update tests to reflect new decision rules for wall proximity.
    [cell_motion.c]

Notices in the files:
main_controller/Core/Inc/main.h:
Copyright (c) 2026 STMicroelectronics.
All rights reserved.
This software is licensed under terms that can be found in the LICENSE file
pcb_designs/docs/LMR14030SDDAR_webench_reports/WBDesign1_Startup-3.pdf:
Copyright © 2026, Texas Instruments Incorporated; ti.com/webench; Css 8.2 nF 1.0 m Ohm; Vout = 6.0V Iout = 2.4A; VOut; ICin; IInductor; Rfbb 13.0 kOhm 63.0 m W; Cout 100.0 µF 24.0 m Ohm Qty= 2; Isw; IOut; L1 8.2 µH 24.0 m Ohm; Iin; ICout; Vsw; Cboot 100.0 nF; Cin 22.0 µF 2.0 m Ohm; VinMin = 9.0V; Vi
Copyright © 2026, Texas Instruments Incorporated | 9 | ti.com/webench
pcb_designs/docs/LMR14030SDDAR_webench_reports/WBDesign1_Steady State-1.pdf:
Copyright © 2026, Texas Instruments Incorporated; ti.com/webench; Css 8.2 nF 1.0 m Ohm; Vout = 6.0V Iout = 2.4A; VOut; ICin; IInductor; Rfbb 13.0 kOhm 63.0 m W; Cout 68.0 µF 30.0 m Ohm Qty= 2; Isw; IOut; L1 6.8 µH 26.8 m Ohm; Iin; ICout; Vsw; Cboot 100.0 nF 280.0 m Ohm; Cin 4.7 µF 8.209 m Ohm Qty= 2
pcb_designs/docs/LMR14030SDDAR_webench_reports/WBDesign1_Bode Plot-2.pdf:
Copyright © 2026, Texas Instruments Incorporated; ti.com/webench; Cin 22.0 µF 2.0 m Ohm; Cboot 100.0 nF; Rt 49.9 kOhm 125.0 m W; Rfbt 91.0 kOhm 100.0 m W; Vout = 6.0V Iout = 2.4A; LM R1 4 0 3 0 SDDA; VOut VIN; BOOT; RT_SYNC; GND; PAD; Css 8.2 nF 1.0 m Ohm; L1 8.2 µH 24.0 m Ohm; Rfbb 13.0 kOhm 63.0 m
